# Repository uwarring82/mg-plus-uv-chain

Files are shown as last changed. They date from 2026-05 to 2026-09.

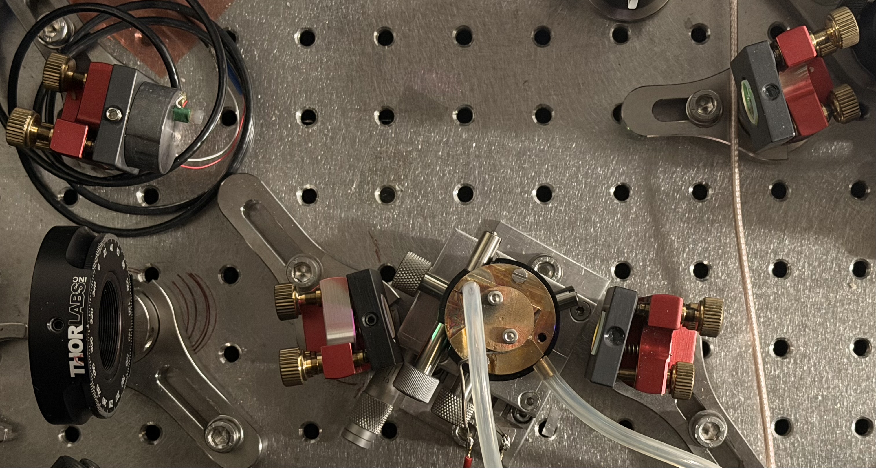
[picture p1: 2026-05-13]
docs/assets/components/home-built-doublers/bermuda-raman-bbo-doubler-2026-05.jpeg

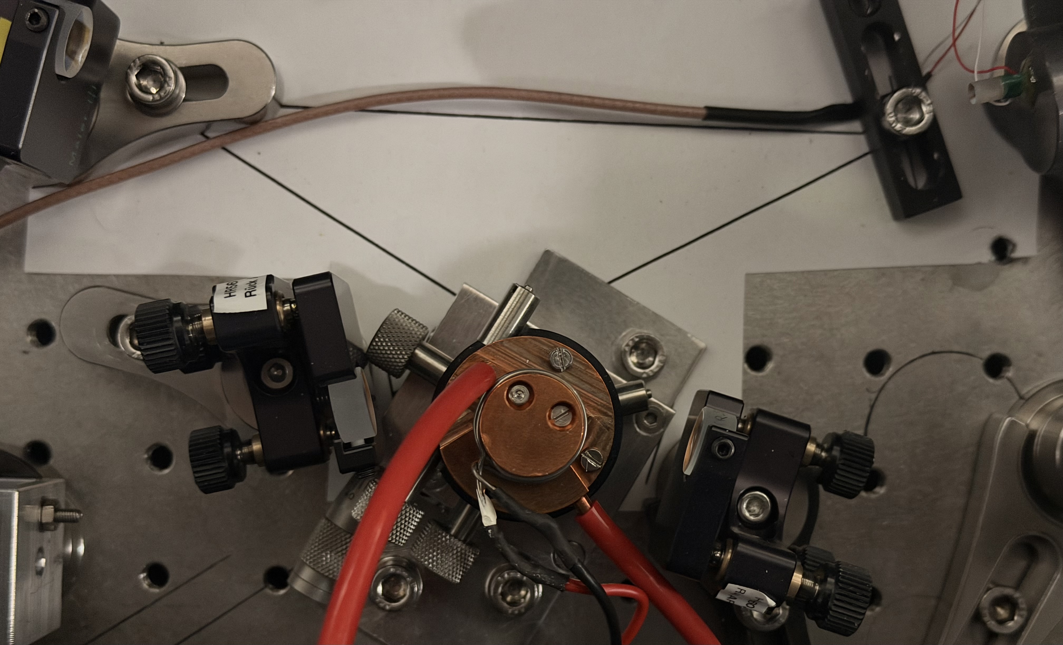
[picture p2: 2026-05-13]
docs/assets/components/home-built-doublers/bermuda-rd-bbo-doubler-2026-05.jpeg

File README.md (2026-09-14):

# mg-plus-uv-chain

UV source redesign for ²⁵Mg⁺ detection, cooling, and coherent control.

A reproducible, version-controlled, FAIR design effort to redesign the all-solid-state CW laser source producing radiation near 280 nm for trapped ²⁵Mg⁺. Successor to Friedenauer *et al.*, *Appl. Phys. B* **84**, 371 (2006).

**Status — checked 2026-09-09.** The [literature dossier index](docs/KD-2026-XXX-uv-280nm.md#entry-index) records **9 of 15 entries past SCAFFOLD** (8 POPULATING, 1 DRAFT). These are dossier topics, distinct from the **22 per-paper extraction files** under [data/literature/](data/literature/). The [September review card](logbook/2026-09-09-repository-review-task-card.md) tracks numerical corrections and documentation work; the [correction record](logbook/2026-09-09-public-record-corrections.md) records progress. The [inventory](docs/components/inventory.md#agile-receipt) includes the Agile mirror receipt and selected coating data.

Phase 2 baseline measurement remains unblocked. G1 and G2 remain OPEN; G3 has been CLOSED since 2026-05-01 (reference triple locked). Architecture-specific simulation and degradation-dependent comparison inputs remain subject to their [gate conditions](#status-of-kill-gates-charter-51). The Charter remains frozen at v1.0.

**Steward.** Ulrich Warring (Albert-Ludwigs-Universität Freiburg, AG Schätz).

**Project site (GitHub Pages).** [Project overview](https://uwarring82.github.io/mg-plus-uv-chain/), built from `main:/docs` using Jekyll. The site introduces the optics, calculations and current status. Borrowed visual assets use **Handbook (MIT)** licensing and **Model B (distributed copies pinned by checksum)**; attribution and hashes are in [asset provenance](docs/assets/SOURCE.md).

---

## Quick navigation

This repository is governed by the [Charter](CHARTER.md). The Charter is the canonical reference; this README is a navigational index.

**If you want to know…**

| Question | Look in |
|---|---|
| Why this redesign exists, and what it is *not* | [CHARTER.md §1, §3](CHARTER.md) |
| What constraints flow from the ion physics down to the source | [CHARTER.md §1.5](CHARTER.md) (Level 0 → Level 1 → Level 2) |
| What "≥ 500 mW at 280 nm" actually means | [CHARTER.md §2](CHARTER.md) and [`constraints/`](constraints/) |
| Which architectures are on the table | [CHARTER.md §4](CHARTER.md) (quadrupling / SFG / hybrid / direct deep-UV) |
| The phase plan and what blocks what | [CHARTER.md §5, §5.1, §5.3](CHARTER.md) (phases, kill-gates, gate closure protocol) |
| How architectures will be compared | [CHARTER.md §5.2](CHARTER.md) (six fixed scoring axes, reference-triple anchoring) |
| What "success" means | [CHARTER.md §6](CHARTER.md) |
| Known unsolved boundaries (14-GHz domain, UV degradation, coatings) | [CHARTER.md §8](CHARTER.md) |
| Governance, vetoes, logbook discipline | [CHARTER.md §9](CHARTER.md) |
| Why the Charter has the shape it does | [`logbook/2026-04-30-kickoff.md`](logbook/2026-04-30-kickoff.md) (nine-cycle deliberation history) |
| How students can learn, run notebooks and contribute | [Student tutorials](https://uwarring82.github.io/mg-plus-uv-chain/tutorials/) |
| Where the SHG mechanical drawings and machine-readable design records live | [SHG design archive](https://uwarring82.github.io/mg-plus-uv-chain/components/shg-designs.html) · [source records](data/designs/shg/) |
| How to cite this work | [`CITATION.cff`](CITATION.cff) |

---

## Repository layout

Selected paths present in the repository:

```text
mg-plus-uv-chain/
├── CHARTER.md                  Frozen at v1.0; canonical design document
├── README.md                   This file
├── CONVENTIONS.md              Units, code and contribution conventions
├── CITATION.cff                Software citation metadata
├── LICENSE                     MIT (code)
├── LICENSE-DOCS                Document-licence scope and prior declaration
├── LICENSES.md                 Licence map and pending assignments
├── endorsement.md              Historical scope and attribution record
├── src/
│   ├── parameters.py           SI constants and locked reference values
│   └── boyd_kleinman.py        One of the generic optical-model utilities
├── constraints/                Constraint derivations; draft status noted in each file
│   ├── raman-requirements.md
│   ├── loss-budget.md
│   └── phase-noise-budget.md
├── docs/
│   ├── KD-2026-XXX-uv-280nm.md  Literature dossier (Phase 1)
│   ├── architectures/          Candidate sketches and requirements
│   ├── components/             Baseline, stock inventory and seed-laser records
│   ├── tutorials/              Generated tutorials and supporting documentation
│   ├── hardware-status.md     Dated hardware record
│   └── status.md              Dated phase/gate snapshot
├── tests/                      Numerical tests and import guards; CI work in RC-06
├── notebooks/                  Tutorial sources, diagnostics and explorations
├── scripts/                    Rendering and conversion tools
├── data/
│   ├── README.md               Data layout and measurement-metadata conventions
│   ├── literature/             Per-paper extractions and notes
│   └── lab notes/              Converted lab records; private attachments excluded
└── logbook/
    ├── _templates/
    │   └── gate-closure.md     §5.3 template
    └── 2026-09-09-repository-review-task-card.md
```

**Planned, not yet present:** `data/baseline/` for Phase 2 measurement deposits,
and `docs/architecture-comparison.md`, `docs/stability-budget.md` and
`docs/degradation-protocol.md` as dedicated outputs. Current architecture
requirements live under [docs/architectures/](docs/architectures/); measurement
metadata conventions are in [data/README.md](data/README.md).

---

## Status of kill-gates (CHARTER §5.1)

| Gate | Blocks | Status |
|---|---|---|
| G1 | Phase 3 architecture-family-specific simulation | OPEN — awaiting Phase 2 attribution of 14-GHz domain |
| G2 | Phase 4 / Phase 5 acceptance of degradation rate | OPEN — awaiting Phase 2 §8.2 protocol reproducibility |
| G3 | Phase 4 architecture comparison | **CLOSED** 2026-05-01 — see [`logbook/2026-05-01-gate-g3-closure.md`](logbook/2026-05-01-gate-g3-closure.md) |

Gate closure requires the recorded acknowledgement defined in Charter §5.3, using [`logbook/_templates/gate-closure.md`](logbook/_templates/gate-closure.md).

---

## How to contribute

Ulrich Warring is accountable for this project. External issues, suggestions and technical reviews are welcome. Changes to Charter §1.5 Level 0/1 constraints, §6 success criteria or gate closures require a recorded review under Charter §9. The historical `council-3` issue label identifies that review process; it does not imply a separately staffed committee.

The Charter is frozen at v1.0. Revisions require a documented v1.x cycle.

---

## Citation

If this repository or its outputs inform your work, please cite as in [`CITATION.cff`](CITATION.cff). A Zenodo DOI has not been verified. No tags or GitHub releases were present on the remote when checked on 2026-09-09. Cite the repository and the commit used; the frozen Charter version is not evidence of a tagged software release.

## License

Licensing is specified by content in the [licence map](LICENSES.md):

- **Coastline — CC-BY-SA-4.0:** mapped framework and navigation documents, including this README; attribution and ShareAlike apply.
- **Sail — CC-BY-NC-SA-4.0:** mapped authored analyses; attribution, NonCommercial and ShareAlike apply.
- **Handbook — MIT:** borrowed site assets and mapped layouts. **Code — MIT.**
- **Data — CC-BY-4.0:** mapped structured extractions and measurement data.

These are licence categories, not ratings of scientific confidence. The map
records remaining scope questions and prior declarations; third-party sources
retain their own terms. [LICENSE-DOCS](LICENSE-DOCS) explains document scope.

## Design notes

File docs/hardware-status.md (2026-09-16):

---
layout: default
title: Hardware status — VECSEL seed fleet
description: What has been built and what is open on the in-house VECSEL seed lasers (1118 nm cooling/detection/Raman and 1141 nm photoionisation), distilled from the lab record. Operational snapshot, sanitised; distinct from the governance Status page.
---

<p class="endorsement"><strong>Endorsement Marker.</strong> Local operational snapshot — AG Schätz stewardship. This page summarises the build/operations state of the in-house VECSEL seed fleet at a sanitised level (roles, not individuals; no procurement or facility detail). It is not a Phase 4 input and does not alter the reference triple. For repository governance state (kill-gates, phases, dossier) see the <a href="status.html">Status</a> page.</p>

<p class="eyebrow">Snapshot · 2026-06-26 · DRAFT</p>

# VECSEL seed fleet — what's done, what's open.

Distilled from the internal lab record (2021–2026) into a sanitised summary, so the group
can see at a glance what has been built and what is still open. Figures are
**[in-house, unverified]** pending cross-check against the primary logbook; the provenance
artefact is [`data/lab notes/2026-06-rnd-vecsel-channel-record.md`](https://github.com/uwarring82/mg-plus-uv-chain/blob/main/data/lab%20notes/2026-06-rnd-vecsel-channel-record.md).

For *how* the lasers work, see the [VECSEL systems tutorial](tutorials/vecsel-systems.html).

---

## The fleet *Sail*

<p class="classification classification--sail">Sail · operational state; the testable physics is in the tutorial and the cited lab notes.</p>

| Unit | Wavelength / role | State (2026-06) |
|---|---|---|
| **"Heidi" (V#2)** | **1141 nm** photoionisation → extra-cavity **LBO → ≈570 nm** (toward 285 nm) | Lasing; doubling stage commissioned 2026 (≈570 nm output measured) |
| **1118 nm units (incl. V#4)** | cooling / detection / repump / Raman seed → 280 nm | In operation; V#4 in use by a downstream experiment |
| **V#5** (1118 nm, student build) | cooling/detection-class seed | Operating ~2.6 W; Lyot-filter re-fit in progress (see open items) |
| **"NeXt"** (1118 nm, bachelor build) | next-generation low-noise platform | Re-lased; integrated onto its cold plate |

---

## What has been done *Coastline + Sail*

<p class="classification classification--coastline">Coastline · the linewidth lineage is the published in-house record (tutorial §3.3).</p>

- **Linewidth driven down > 10× across four builds** — 1.6 MHz (2021) → ~300–400 kHz (2023) → **101(8) kHz locked (2025)**, by closing thermal, mechanical, and cooling-water noise sources (tutorial [§3.3](tutorials/vecsel-systems.html)).
- **A facility-plumbing finding** — a chiller on/off cycle drove ~200 MHz of frequency oscillation; replacing the cooling loop removed it (factor-5 short-term gain).
- **Multiple operating units** built and characterised at 1118 nm (cooling/detection/Raman) plus the 1141 nm photoionisation unit.
- **1141 nm → ≈570 nm doubling stage** stood up in 2026 (extra-cavity LBO ring; ~110 mW measured in one run) — the first SHG step toward 285 nm.
- **1118 nm operating point** recently re-confirmed on the V#5 build (~2.6 W near 267.744 THz, 2026).

---

## Open items *Sail*

<p class="classification classification--sail">Sail · current work fronts; none of these alters Charter Level 0/1 constraints or the kill-gate state (see <a href="status.html">Status</a>).</p>

**Measurement gaps (also tracked in the tutorial §3.5 / §5):**
- **Seed frequency-noise PSD** across the doubling-cavity servo band — unmeasured. The closed-loop bandwidth of each doubling cavity is itself unmeasured; Friedenauer 2006's ≈ 18 kHz is a loaded piezo resonance, not a loop bandwidth (see [planned cavity-lock electronics](components/shg-designs.html#cavity-lock-electronics)).
- **Downstream UV relative-intensity noise** at the experiment — unmeasured.
- A true **sub-100 kHz intrinsic linewidth** — not yet independently proven (needs delayed self-heterodyne or a beat note).
- **1141 nm "Heidi"** full characterisation — linewidth, output power, and the ≈570 nm → 285 nm second stage still to be recorded.

**Build / commissioning fronts** (engineering status; none affects the physics above):
- **1141 → 570 nm doubling lock** under stabilisation (commissioning in progress).
- **V#5 (student build):** intracavity birefringent (Lyot) filter re-fit in progress; single-mode hold time temporarily reduced in the interim.
- **New gain-chip mounting:** a freshly-mounted chip shows a slow (~10 min) power/frequency settling, under characterisation.
- **"NeXt":** water-cooling vibration test and control-board revision pending.

---

## See also

- [Status](status.html) — repository governance state (kill-gates, phases, dossier, tests).
- [VECSEL systems tutorial](tutorials/vecsel-systems.html) — how the seed lasers work and what limits their linewidth.
- [`data/lab notes/`](https://github.com/uwarring82/mg-plus-uv-chain/tree/main/data/lab%20notes) — the sanitised in-house extractions every figure here is drawn from.

---

[← Home](index.html) · [Status →](status.html) · [VECSEL tutorial →](tutorials/vecsel-systems.html)

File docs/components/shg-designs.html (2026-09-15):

--- layout: default title: SHG mechanical designs — AG Schaetz description: Original LBO and BBO drawings, open CAD exports, and a machine-readable catalogue with provenance and conversion limitations. ---

AG Schaetz · Mechanical design archive · 2020–2021

# Inside our SHGs

Explore the cavities, crystal mounts and optical assemblies behind the laboratory's frequency-doubling chain. Each design has an unchanged original, an open drawing export and a record of what the conversion preserves.

{{ site.data.shg.designs.size }} drawings · Author: AG Schaetz · Publication authorized by Ulrich Warring, 14 September 2026.

Download JSON catalogue JSON Schema Source archive & YAML records (https://github.com/uwarring82/mg-plus-uv-chain/tree/main/data/designs/shg)

Readable previews; conversion fidelity unverified.

These views are reconstructed from cached drawing blocks. An independent CAD rendering has not yet been checked. Some engineering symbols may appear as letters because the original AIGDT font is unavailable; view placement and clipping may differ. Use the original CAD for manufacturing decisions.

This archive documents existing designs. It is not a build commitment for the next-generation source, and correspondence to installed hardware requires a bench check.

How to read and reuse this archive

DWG is the byte-identical source. DXF.gz is an ASCII DXF export compressed for download; decompress it before opening it in CAD software. SVG, PDF and PNG are preview derivatives. Source files, exports and previews have individual SHA-256 checksums in the catalogue.

DWG JSON.gz preserves the source reader's object graph for programmatic use: handles, coordinates, classes and opaque proxy payloads. It is a drawing export under CERN-OHL-S-2.0. The separate JSON catalogue contains CC-BY-4.0 metadata.

The source uses Inventor proxy objects with cached linework. The exports preserve accessible drawing entities and annotations; editable native models and STEP exports are not established. Inspection records expose annotation text with entity handles, entity counts, layout decisions and conversion limitations.

The block audit (https://github.com/uwarring82/mg-plus-uv-chain/blob/main/data/designs/shg/block-audit.json) accounts for the identical entity deficits in eight drawings: ODA omits two repeated template blocks, a sheet border and historical title block. Their stored insertion backlinks are absent from the parsed source graph. This identifies the omitted content; proxy semantics and rendering fidelity remain unverified.

Design only means no installed-hardware association has been established. Provisionally associated requires cited evidence. Confirmed requires a bench check. A match to a thesis drawing is not hardware confirmation.

Guth2021 §2.2.2 is a starting reference. The geometry extraction (https://github.com/uwarring82/mg-plus-uv-chain/blob/main/data/literature/Guth2021/geometry.yaml) preserves printed values, including the unresolved LBO curvature entry of 50 cm in Table 3. No drawing-to-thesis dimensional match is asserted yet.

Drawings, exports and preview images: CERN-OHL-S-2.0 (https://ohwr.org/licences/). Catalogue metadata: CC-BY-4.0. Page narrative: CC-BY-SA-4.0. Tooling: MIT. See the scoped licence notice (https://github.com/uwarring82/mg-plus-uv-chain/blob/main/data/designs/shg/LICENSE.md) and decision and validation record (https://github.com/uwarring82/mg-plus-uv-chain/blob/main/logbook/2026-09-14-shg-design-publication.md).

Cavity-lock electronics (planned)

AG Schaetz plans to lock the LBO and BBO cavities with the digital PID controller developed at PTB and described by Hannig et al. (2018) (https://doi.org/10.1063/1.5005515). Later work calls it "PTB-PID". The technical description below comes from public sources. No settings, measured lock performance or hardware assignment are reported for our cavities, and the published source code has not been matched to the firmware on the laboratory units. This plan leaves project parameters and gate status unchanged.

Published design. Hannig et al. lock a Brewster-cut BBO cavity (626 nm → 313 nm) using a Hänsch–Couillaud error signal from a polarization analyser and differential photodiode. The PI output drives a piezo-mounted cavity mirror; the D term is set to zero for cavity locking. The controller is a modified STEMlab 125-14 (formerly Red Pitaya). The PID algorithm runs in the FPGA of a Xilinx Zynq-7010 system-on-chip, independently of the embedded software. It uses two fast analog input channels and two output channels at 125 MS/s with 14-bit nominal resolution. Parameters are set through a web application, a serial connection or a standalone touchscreen and rotary encoder. The paper explicitly states that the board hardware is not open source; the modified application source is publicly available (§IV.C).

Additions to the stock PID. The controller adds a master gain, a second integrator, an output offset, extended parameter ranges and an integrated signal generator. It can save settings and digitally limit its output. An auxiliary intensity input enables automatic relocking by distinguishing TEM00 resonances from parasitic signals, and it provides automatic integrator reset and sample-and-hold. The standalone box amplifies the DAC output eightfold (2 Vpp to 16 Vpp) for the piezo and includes a modification that reduces DAC output noise.

Reported limits and results. The controller's 155 ns group delay suggests a maximum closed-loop bandwidth of a few MHz; effective converter resolution is below 14 bits (§IV.D.2). This is a controller-delay estimate: the published piezo connection also includes a 21.2 kHz low-pass filter (§IV.C.1). In Hannig's cavity, a broad resonance near 17 kHz set the upper limit for locking bandwidth; the authors attribute it provisionally to the mirror, piezo actuator and holder (§V.B). They report 130 h of uninterrupted lock and, in a separate acceleration test, lock retention up to about 1 g with output-power variation at the 10 % level (§V.A, C).

Friedenauer (2006) reports a similar loaded piezo resonance of about 18 kHz for the LBO cavity (§3, p. 372). That resonance is not a measurement of closed-loop bandwidth. Neither paper establishes the bandwidth of our planned locks; that requires measurements of the assembled systems.

Public sources.

- S. Hannig et al., "A highly stable monolithic enhancement cavity for second harmonic generation in the ultraviolet," Rev. Sci. Instrum. 89, 013106 (2018), doi:10.1063/1.5005515 (https://doi.org/10.1063/1.5005515) (published article: CC BY 4.0). An accessible 2017 preprint (https://arxiv.org/abs/1709.07188) is also available.
- Controller source cited by the paper (ref. 67): Julia-F/RedPitaya at 7938c27 (https://github.com/Julia-F/RedPitaya/tree/7938c27fc030ca5d8d13b1731f559e33585458f1), a snapshot dated 26 May 2016. The PID application is in apps-free/pid2 and the FPGA logic in fpga/rtl/red_pitaya_pid2*.v. Its COPYING (https://github.com/Julia-F/RedPitaya/blob/7938c27fc030ca5d8d13b1731f559e33585458f1/COPYING) grants BSD terms for an explicit directory list whose names differ from these paths. Licence coverage for the modified controller has not been established here; check the applicable notices before reuse.
- J. Fenske, "Implementierung eines digitalen PID-Reglers mit dem Entwicklungsboard Red Pitaya," BSc thesis, Ostfalia Hochschule für angewandte Wissenschaften (2015). Bibliographic citation from Hannig et al., ref. 42; the thesis itself was not reviewed.
- P. Knauer, "Stabilisation of Thermal Drifts in a Femtosecond Enhancement Cavity," BSc thesis, University of Heidelberg (2019), PDF (https://pure.mpg.de/rest/items/item_3048433_1/component/file_3048434/content), §§3.2 and 4.1. It describes an MPIK adaptation of PTB-PID for a Pound–Drever–Hall lock; the corresponding code is in PatKnauer/redpitaya (https://github.com/PatKnauer/redpitaya).

Find a design Stage or role

{{ site.data.shg.designs.size }} designs

{% for design in site.data.shg.designs %} {% assign first = design.previews | where: "qualifies", true | first %}

{{ design.id }} · {{ design.stage | escape }} · {{ design.kind | escape }}

## {{ design.title_en | escape }}

{{ design.title_de | escape }}

{% if first %} Unverified reconstructed drawing of {{ design.title_en | escape }}, sheet {{ first.name | escape }} {% endif %}

{{ design.hardware_association.status | replace: '_', ' ' | capitalize }} · Preview unverified

Original DWG DXF.gz DWG JSON.gz {% if first %}PDF preview{% endif %}

All sheets & provenance

Original name: {{ design.original_filename | escape }}

{{ design.previews.size }} recorded layouts · Native unit: {{ design.units.native | escape }} · {{ design.classification.basis | escape }}

{% for observation in design.conversion_observations %}

Conversion note: {{ observation | escape }}

{% endfor %}

Conversion and annotation record · Independent source-reader record

{% if design.block_audit_result %}

Template-block audit ({{ design.id }})

{% endif %} {% for sheet in design.previews %} {% if sheet.qualifies %}

{{ design.title_en | escape }}: sheet {{ sheet.name | escape }}, unverified preview

{{ sheet.name | escape }} · SVG · PDF · Unverified

{% else %}

{{ sheet.name | escape }}: {{ sheet.reason | replace: '_', ' ' | escape }}

{% endif %} {% endfor %}

{% endfor %}

No designs match. Try a different name or stage.

Related records: BBO photographic survey · Hardware inventory · Friedenauer reference chain.

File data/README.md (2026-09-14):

# Data — `data/`

**CHARTER §7 FAIR commitment:** raw and processed data separated; metadata schema declared here.

This directory holds all measurement and reference data for `mg-plus-uv-chain`. Empty at v1.0 cut; populated during Phase 1 (literature parameter extraction) and Phase 2 (baseline measurements).

---

## Layout

```
data/
├── README.md                ← this file (metadata schema)
├── baseline/                ← Phase 2 measurements on the existing chain
│   └── YYYY-MM-DD_<topic>/
│       ├── raw/             ← unmodified instrument output
│       ├── processed/       ← analysed; provenance preserved
│       └── metadata.yaml    ← per-dataset metadata (schema below)
└── literature/              ← parameters extracted from cited works
    └── <citation-key>/
        ├── extracted.yaml   ← parameter table
        └── notes.md         ← extraction commentary
```

Per CHARTER §7: raw and processed data are kept in sibling directories, never co-mingled. Provenance from raw → processed must be reconstructible from committed code.

---

## Metadata schema (`metadata.yaml`)

Every measurement dataset under `baseline/` carries a `metadata.yaml` file at its root with the following fields:

```yaml
# Required
dataset_id: "YYYY-MM-DD_<topic>"           # matches directory name
date: "YYYY-MM-DD"                         # ISO 8601
operator: "<name>"                         # who took the data
charter_phase: 2                           # which CHARTER phase this serves
charter_section_refs:                      # which CHARTER sections it informs
  - "§8.1"                                 # e.g. 14-GHz domain discriminant
  - "§8.2"                                 # e.g. degradation tuple

# Apparatus state — reproducibility anchor
apparatus:
  source_chain: "<short description>"      # e.g. "1118 nm fibre amp + 2× SHG, BBO at UV stage"
  source_version: "<git tag or label>"     # if a software-controlled chain
  enclosure_atmosphere: "N2 | O2 | dry-air | ambient"
  ambient_temperature_C: <float>           # if relevant
  exposure_history: "<free-form>"          # CHARTER §8.2: cumulative UV exposure context

# Instruments — every channel that produced a value
instruments:
  - role: "<e.g. UV power meter>"
    make_model: "<vendor / model>"
    serial: "<sn or label>"
    last_calibration: "YYYY-MM-DD"

# Measurement parameters — what was scanned
scan:
  type: "<e.g. cavity-length, polarisation, intra-cavity-intensity>"
  variable: "<symbol>"
  units: "<SI>"
  range: [<low>, <high>]
  step: <float>
  averaging: <int>                          # samples per point

# Data files — pointer with units
files:
  - path: "raw/<file>"
    columns:
      - name: "<symbol>"
        units: "<SI>"
        description: "<one line>"

# Discriminant hypothesis (if applicable; CHARTER §8.1)
discriminant:
  hypothesis_under_test: "<text>"
  expected_signature: "<text>"
  outcome_classification: "Resolved | Operationally bounded | Underdetermined | TBD"

# Provenance — raw → processed
processing:
  pipeline: "<git path to processing script>"
  pipeline_commit: "<sha>"
  random_seed: <int>                        # required if any stochastic step
  inputs: ["raw/<file>", ...]
  outputs: ["processed/<file>", ...]

# Notes
notes: |
  Free-form commentary. Anything that would be needed to interpret this
  dataset six months later, or by an outside reader, goes here.
```

All units are SI per CONVENTIONS §1. Derived-unit presentation (mW, nm, GHz) lives in plotting code, not in the metadata file.

---

## Literature data (`literature/<citation-key>/`)

Per-paper parameter extractions live under `literature/<citation-key>/extracted.yaml`:

```yaml
citation_key: "Friedenauer2006"             # matches CITATION.cff and dossier
doi: "10.1007/s00340-006-2274-2"
extracted_by: "<name>"
extracted_on: "YYYY-MM-DD"
charter_section_refs: ["§2", "§4", "§8.1"]

parameters:
  - symbol: "P_UV"
    value: 0.275
    units: "W"
    location_in_paper: "Abstract; Fig. 3"
    notes: "Reported source-side; loss budget to ion not stated."
  - ...
```

Vendor / batch sensitivity, where the paper reports it, must be captured (CHARTER §5 Phase 1 evidence-table requirement).

## Design data (`designs/`)

The [AG Schaetz SHG archive](designs/shg/README.md) separates unmodified
CAD in `designs/shg/raw/` from exports and inspection records in
`designs/shg/processed/`. Its canonical `catalogue.yaml` is validated by
`catalogue.schema.json`; this design schema is separate from the baseline
measurement schema above.

Each drawing also has a compressed ASCII DXF and a compressed GNU LibreDWG
JSON object graph. The latter exposes source objects and opaque payloads to
programmatic readers; it carries the hardware licence. Compact inspection
JSON and the generated catalogue carry the metadata licence.

Required design records include stable IDs independent of filenames, original
names and archive-name encoding, author attribution, publication/licence
disposition, checksums, part/assembly classification, source and converter
date metadata, native units, hardware-association evidence, export inventories,
layout decisions, conversion losses and preview references. Original CAD units
and raw annotations are preserved; normalized extracted quantities use SI.
Hardware confirmation requires bench evidence. Drawing tags `D`, `D*`, `OPEN`
identify direct, ambiguous/inferred and unresolved evidence.

`scripts/shg_designs.py site` generates `docs/_data/shg.yml` and the public
JSON catalogue from canonical YAML. Its `check` command verifies schema,
file hashes and generated-data freshness. The new `tests/test_shg_designs.py`
covers these contracts. Licence scope for CAD, metadata, derivatives and
narrative is explicit in [LICENSES.md](../LICENSES.md); it is not inferred
from the existing measurement-data or site-asset categories.

---

## Charter compliance

- **Pre-G1**: data may be deposited freely; data ingest does not constitute architecture-family-specific simulation under CHARTER §5.1.
- **Discriminant scans (CHARTER §8.1)**: deposited under `baseline/`; `outcome_classification` tracks per-scan progress toward G1 closure.
- **Degradation protocol (CHARTER §8.2)**: time-resolved {power, M², phase noise, polarisation} mandatory. Single-number degradation rates without protocol attribution will be rejected per the Charter.
- **§9 trigger question**: depositing data does not by itself change a Level 0/1 parameter. If interpreting the data prompts a constraint change, that's an architectural decision and lives in `/logbook/`.

---

End of `data/README.md`.

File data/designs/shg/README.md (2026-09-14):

# AG Schaetz SHG design archive

**Author attribution:** AG Schaetz. **Publication authorized:** Ulrich Warring,
2026-09-14. [Decision and work record](../../../logbook/2026-09-14-shg-design-publication.md)
and [publication follow-ups](../../../logbook/2026-09-14-shg-publication-follow-ups.md).

The archive preserves 28 drawings supplied as `SHG.zip`. Originals retain
their exact bytes under stable IDs. The ZIP checksum, original filenames,
original filename bytes, local ZIP timestamps and individual checksums are
in [`catalogue.yaml`](catalogue.yaml). Finder timestamps and drawing creation
dates are separate evidence; ZIP timestamps have no recorded timezone.
`.DS_Store` and `__MACOSX` are excluded. IDs are an explicit registry, not
calculated from filenames or contents.

## Formats and limitations

- `raw/SHG-NNN.dwg`: unmodified AC1032 DWGs.
- `processed/SHG-NNN/SHG-NNN.dxf.gz`: direct ODA ACAD2018 ASCII DXF export,
  compressed without modifying its contents. Decompress with `gzip -dk` or
  Python `gzip.decompress`. Both compressed and uncompressed hashes are recorded.
- `processed/SHG-NNN/source-inspection.json`: source-side counts, original
  DWG date fields and warnings from GNU LibreDWG.
- `processed/SHG-NNN/SHG-NNN.dwg.json.gz`: the complete GNU LibreDWG reader
  object graph, including handles, coordinates, source classes and opaque
  proxy payloads. Decompress, then parse as JSON. This is a drawing export
  under CERN-OHL-S-2.0, distinct from the CC-BY-4.0 catalogue metadata.
- `processed/SHG-NNN/inspection.json`: DXF entity inventories, annotation
  text with source handles, references, reconstruction placements and losses.
- `docs/assets/shg/SHG-NNN/`: generated PDF/SVG/PNG previews for each
  qualifying sheet. These are **unverified reconstructed previews**.

The drawings use Inventor-specific proxy objects with cached linework and
annotation blocks. The direct exports preserve those blocks but do not
constitute editable native Inventor models. Ordinary layout rendering is
empty without exposing the cached blocks. The preview tool decodes the
observed unit-transform proxy variant, exposes blocks at their stored
coordinates, and applies source viewport associations, scale and clipping.
Unfamiliar transforms stop processing. This restricted decoder and the
resulting views remain unverified against an independent CAD engine.
The AIGDT engineering
symbol font is unavailable; some symbols appear as letters. **Use original
CAD and an independent CAD reference before machining or relying on dimensions.**

LibreDWG provides a second parse, not an independent rendering. Reader
success, matching counts and visual legibility do not establish fidelity.
Source-side dates are retained as raw day/millisecond pairs; ODA can reset
the DXF date fields, so those are labelled converter metadata. Native solids
and STEP availability are unresolved inside the proxy payloads. No STEP or
interactive 3D export is asserted.

The [block audit](block-audit.json) identifies the identical deficit in eight
drawings as omitted sheet-border (`D3`) and historical title-block (`FC`)
definitions. Both source names are `*I`; preserved handles distinguish them.
Their recorded insertion backlinks are absent from the parsed source graph.
The full deficit is accounted for, but opaque proxy references and visual
effect still need an independent CAD check. Reproduce with
`python -m scripts.shg_block_audit --check` in the full SHG environment.

## Native source and reference-rendering follow-up

No `.iam`, `.ipt`, `.idw` or `.ipj` files were found in the supplied archive,
repository or the Desktop filename search on 2026-09-14. Their location
remains an open request to the Steward; this is not a claim about other
laboratory storage. The preferred handover is an Inventor
[Pack and Go package](https://help.autodesk.com/cloudhelp/2025/ENU/Inventor-Help/files/GUID-730304AA-13BD-467B-9351-C7C1362876BD.htm)
with assemblies, parts, drawings, the project file and resolvable references.
Include referencing drawings and required libraries when collecting the
package, and record the authoring version and any missing references/fonts.

Receiving native files alone does not verify these previews. Render the
corresponding sheets with Inventor, or use an independent AutoCAD rendering
of the original DWGs, then compare dimensions, symbols, layouts and views
per file. Native assembly relationships and STEP exports require separate
checks. Hardware confirmation still requires bench evidence.

## Records and evidence

[`catalogue.schema.json`](catalogue.schema.json) validates the YAML record.
Drawing evidence tags are `D` (direct), `D*` (ambiguous/inferred), `OPEN`
(unresolved). These are separate from hardware association: `design_only`,
`provisionally_associated`, `confirmed`. The last requires bench evidence.
Guth2021 correspondence alone cannot confirm installed hardware; the
[targeted geometry extraction](../../literature/Guth2021/geometry.yaml)
records printed parameters and unresolved discrepancies.

The initial numerical extraction is deliberately limited. Inspection reports
preserve all accessible annotation text and handles, including exploded
dimension labels, but do not turn a label into a measured feature. Materials
and tolerances remain OPEN unless supported by a title block. Native CAD
units are retained; normalized numerical catalogue fields use SI.

## Reproduction

For the complete SHG test and rendering environment, run
`python -m pip install -e '.[test,shg]'` from the repository root. The `shg`
extra pins the same drawing dependencies as
[`scripts/requirements-shg.txt`](../../../scripts/requirements-shg.txt).
The standard `test` extra does not install ezdxf: the two viewport tests
skip without it. Run pytest with `-rs` to see these skip reasons. The
original **14 passed** result used the full drawing environment; the
standard environment instead reports **12 passed, 2 skipped** for that
original test file. There is currently no CI enforcing these checks.
ODA File Converter 27.1.0 and GNU LibreDWG 0.14 are external local tools;
neither tool nor the local Guth thesis PDF is redistributed here.

```sh
python scripts/shg_designs.py ingest /path/to/SHG.zip
python scripts/shg_designs.py convert --oda /path/to/ODAFileConverter --output /tmp/shg-dxf
python scripts/shg_designs.py inspect-source --reader /path/to/dwgread
python scripts/shg_designs.py process /tmp/shg-dxf
python scripts/shg_designs.py site
python scripts/shg_designs.py check
python -m pytest tests/test_shg_designs.py
```

`site` writes `docs/_data/shg.yml` and `docs/assets/shg/catalogue.json` from
canonical YAML. `check` validates the schema, original/export/preview hashes
and generated record freshness. Conversion is separate from website
generation, so checking or publishing the catalogue needs no proprietary
converter. Font availability can change rendering; record it when regenerating.

## Licence

DWGs, derived drawing exports and previews: **CERN-OHL-S-2.0**.
Catalogue metadata: **CC-BY-4.0**. This narrative: **CC-BY-SA-4.0**.
Scripts, schema and tests: **MIT**. See [LICENSE.md](LICENSE.md) for scope,
notices and the source location. Vendor components retain any applicable
third-party notices; this record makes no completeness claim for fabrication.

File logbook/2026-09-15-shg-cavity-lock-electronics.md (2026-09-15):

# SHG catalogue: planned cavity-lock electronics

**Date:** 2026-09-15\
**Steward:** Ulrich Warring\
**SHG design author attribution:** AG Schaetz\
**Licence:** CC-BY-SA-4.0\
**Starting revision:** `12dffc02c4ea57602e1b44cebf443146256635d0`\
**Status:** Published; local checks and live GitHub Pages verification passed.

## Charter §9 triggers

- Affects Level 0 parameters? No.
- Affects Level 1 parameters? No.
- Affects success criteria or gate state? No.

G1 and G2 remain OPEN. G3 remains CLOSED (2026-05-01). This entry records
presentation of the Steward's controller plan and corrections to literature
descriptions. It does not establish controller settings, performance,
firmware identity, installed-hardware association or a next-generation
architecture selection. All 28 drawing records remain `design_only` and
their previews remain `unverified`.

## Decisions

The Steward supplied an uncommitted catalogue subsection for visitors who
cannot access the laboratory's private controller records. The existing
authorization to publish SHG work and instruction to keep logbook entries
apply to this follow-up.

1. Keep the collapsible **Cavity-lock electronics (planned)** section after
   **How to read and reuse this archive**, at
   [`shg-designs.html#cavity-lock-electronics`](../docs/components/shg-designs.html#cavity-lock-electronics).
   The catalogue remains the public reference; no separate page is needed.
2. Omit the private repository's name and link. The public explanation is
   self-contained. No private repository content was accessed in this review
   or included in these changes.
3. Add a pointer from the photo survey's **HC servo electronics and bandwidth**
   gap. The stated intention is to use the PTB digital PID for LBO and BBO
   cavity locks. This intention comes from the Steward; technical descriptions
   and reported results come from the cited public literature.
4. Record the work here despite the absence of parameter changes, following
   the Steward's instruction to keep SHG work records. The existing catalogue
   narrative assignment and this entry are CC-BY-SA-4.0; the root licence map
   explicitly lists this new entry. Existing component-page and literature-note
   assignments are preserved. Public citations do not relicense third-party
   hardware or software.

## Source review and qualifications

The local publisher copy of
[Hannig et al. (2018)](https://doi.org/10.1063/1.5005515), §§IV–V,
pp. 013106-5–8, was checked for the controller and lock claims. The catalogue
also links the [2017 arXiv preprint](https://arxiv.org/abs/1709.07188) for
public access when the publisher blocks a request.

- §IV.C specifies FPGA PI operation with D set to zero, the modified
  STEMlab 125-14, two fast input and two output channels, interfaces,
  controller additions and eightfold output amplification. Its hardware
  subsection explicitly says that the board hardware is not open source.
  The earlier blanket description in
  [`Hannig2018/notes.md`](../data/literature/Hannig2018/notes.md) is corrected;
  the machine-readable extraction remains a scaffold.
- §IV.D.2 derives a few-MHz controller-bandwidth estimate from 155 ns group
  delay. The complete system also includes the 21.2 kHz piezo low-pass filter
  described in §IV.C.1. The estimate is not presented as measured cavity
  bandwidth.
- §V.B identifies a broad resonance near 17 kHz as the lock-bandwidth upper
  limit, probably due to the mirror, piezo and holder. The 130 h lock record
  (§V.A) and acceleration test up to about 1 g (§V.C) are separate results
  from the published 313 nm cavity.
- Friedenauer 2006 §3, p. 372, reports an approximately 18 kHz **loaded LBO
  piezo resonance**, not a measured closed-loop bandwidth. Similar resonance
  frequencies do not establish identical loop limits or any performance of
  the laboratory units. The linked baseline, photo survey and seed-laser
  pages were corrected where they equated that resonance with a measured
  loop bandwidth or assigned it to fielded doublers. The seed-linewidth
  budget and project parameters were not changed.

The code cited by Hannig ref. 67 is linked at
[`Julia-F/RedPitaya`, commit `7938c27fc030ca5d8d13b1731f559e33585458f1`](https://github.com/Julia-F/RedPitaya/tree/7938c27fc030ca5d8d13b1731f559e33585458f1),
dated 26 May 2016. Public `COPYING`, `apps-free/pid2/src/pid.c` and
`fpga/rtl/red_pitaya_pid2.v` were inspected. The explicit BSD directory list
uses different names from the modified controller paths; the two source
headers do not settle coverage. The page states this uncertainty without
using GitHub's automatic licence detection as a legal conclusion. No code
or firmware is imported, and no lab firmware match is claimed.

Fenske's 2015 thesis is cited through Hannig ref. 42; its text was not
reviewed. Knauer's public
[2019 thesis](https://pure.mpg.de/rest/items/item_3048433_1/component/file_3048434/content),
§§3.2 and 4.1 (pp. 20 and 23), and
[`PatKnauer/redpitaya`](https://github.com/PatKnauer/redpitaya) establish the
later PTB-PID/MPIK-PID terminology. This adaptation uses a
Pound–Drever–Hall error signal; it is not evidence of the laboratory's
Hänsch–Couillaud implementation.

## Validation and publication

- `.venv/bin/python -m pytest -q`: **275 passed, 3 skipped**. The existing
  block-audit regeneration and two viewport/proxy tests skip because ezdxf
  is absent from the standard environment. No new test is claimed to cover
  the page's scientific prose.
- The catalogue and default layout rendered with **Liquid 4.0.4** in strict
  parsing/filter mode using `docs/_config.yml` and `docs/_data/shg.yml`.
  This is a local template check, not a local Jekyll build.
- Parsed rendered HTML has balanced tags, unique IDs, 28 design cards, the
  collapsed electronics section in the intended position, and valid local
  fragment targets. Survey and seed-page pointers target the new anchor.
  The private repository identifier is absent from the rendered catalogue.
- Public source checks without authentication return HTTP 200 for the
  pinned code snapshot, its `COPYING`, the arXiv preprint, Knauer's PDF and
  the MPIK code repository. The DOI redirects to the correct publisher
  article, which returns HTTP 403 to the scripted request; the preprint is
  provided as an alternative access route.
- `git diff --check` passes. The new logbook entry is explicitly present in
  `LICENSES.md`. No drawing, export, preview, generated catalogue, simulation
  or parameter data changed.

The existing GitHub Pages source was confirmed as `main:/docs` (legacy
build). Documentation commit
`7a4db92e5cc3cfc24a481171163f55ee5d7e2af0` was pushed to `main`; GitHub Pages
reports that exact commit **built**, with no error, at
2026-09-15 16:07:51 UTC. The first HTTP check during the build still served
the preceding page; checks after completion passed.

The live
[catalogue section](https://uwarring82.github.io/mg-plus-uv-chain/components/shg-designs.html#cavity-lock-electronics)
matches the local rendered section byte for byte, retains all 28 cards and
contains no private repository identifier. Public HTTP checks also confirm
the corrected
[photo survey](https://uwarring82.github.io/mg-plus-uv-chain/components/home-built-doublers.html),
[Friedenauer baseline](https://uwarring82.github.io/mg-plus-uv-chain/components/friedenauer-baseline.html#b2-piezo-and-mount)
and [seed-laser page](https://uwarring82.github.io/mg-plus-uv-chain/components/seed-lasers.html).
The survey/seed pointers resolve to the new section after Jekyll's relative-link
rewriting, and the baseline anchor exists. These are rendered-content and
HTTP checks; no interactive browser test or laboratory validation is claimed.

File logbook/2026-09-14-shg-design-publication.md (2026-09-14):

# SHG design archive: publication and implementation record

**Date:** 2026-09-14\
**Steward:** Ulrich Warring\
**Design author attribution:** AG Schaetz (as explicitly directed by the Steward)\
**Status:** Publication and licence mapping adopted; archive implemented with unverified conversion fidelity.\
**Starting revision:** `909f2919716a2c528536fef1dab331b0f0c83f58`

## Charter §9 triggers

- Affects Level 0 parameters? No.
- Affects Level 1 parameters? No.
- Affects success criteria or gate state? No.

G1 and G2 remain OPEN. G3 remains CLOSED (2026-05-01). This is a record of
existing designs, not a build commitment for the next-generation source.
Conversion and catalogue tools belong in `scripts/`; no cavity simulation is
introduced into `src/`.

## Steward authorization and licence adoption

The Steward instructed: “Go, mention AG Schaetz as author, I authorize
publication, you suggest an open license that fits my philosophy, keep
logbook entries for this work”. Publication authorization covers the SHG
package discussed in this thread. It does not identify individual designers
or establish that a drawing matches installed hardware.

The Steward explicitly answered **“Adopt this licence mapping (recommended)”**
to the proposed mapping on 2026-09-14:

| Artifact | Adopted licence |
|---|---|
| Original DWGs, derived DXF and DWG JSON object graphs, drawing exports and previews | CERN-OHL-S-2.0 |
| Catalogue YAML metadata, generated JSON and `docs/_data/shg.yml` | CC-BY-4.0 |
| Catalogue narrative and this logbook entry | CC-BY-SA-4.0 |
| Conversion/generation scripts, schema and tests | MIT |

CERN-OHL-S-2.0 is a hardware-specific reciprocal licence, consistent with
the project's ShareAlike approach while permitting open use, modification
and distribution. It is a new scoped assignment, not a reinterpretation of
the site's MIT “design assets” row. Existing licence assignments elsewhere
are unaffected. Sources: [CERN overview](https://ohwr.org/licences/),
[licence](https://gitlab.com/ohwr/project/cernohl/-/wikis/uploads/819d71bea3458f71fba6cf4fb0f2de6b/cern_ohl_s_v2.txt).

## Agreed acceptance rules

1. Preserve all 28 DWGs byte for byte; record individual and ZIP SHA-256
   hashes. Omit `.DS_Store` and `__MACOSX`. Stable design IDs are independent
   of filenames; preserve original names and archive-name encoding evidence.
2. Extract Guth2021 §2.2.2 geometry before comparisons. Thesis/design matches
   can only support provisional association; confirmation requires bench
   evidence. Source dimensions, inferred geometry and hardware measurements
   remain distinct.
3. Compare ODA and LibreDWG conversion routes on the baseplate, BBO cavity,
   posts/optomechanics assembly, largest assembly and umlaut filename. All
   files still require individual validation despite sharing AC1032 headers.
4. A reference rendering must use an engine independent of the converter.
   Fidelity is unverified when that reference is unavailable. A successful
   parse or a source thumbnail is not a substitute for this check.
5. A qualifying layout has renderable paper-space content beyond viewport
   frames, or an enabled viewport displaying renderable model-space content
   under its clipping/layer settings. Record every layout's disposition.
   Provide a model-space view when substantive geometry has no such layout.
6. A part describes one manufactured component; an assembly depicts multiple
   identifiable components, including flattened geometry. Annotation blocks
   do not establish assembly status. Unresolved classification cannot waive
   the required part DXF export. Record conversion losses and unavailable
   source-side checks explicitly; do not claim fabrication readiness.
7. Preserve source units; normalize extracted numerical fields to SI. Use
   drawing evidence tags `D` (direct), `D*` (ambiguous/inferred), `OPEN`
   (unresolved), separate from hardware-association status. Materials and
   tolerances require source evidence.
8. Canonical YAML and raw/processed data live under `data/designs/shg/`.
   Declare this layout in `data/README.md`, map licences in `LICENSES.md`,
   and generate the new `docs/_data/shg.yml` and downloadable JSON from it.
   Add new schema, checksum, link and generated-data staleness tests.

STEP and interactive 3D are deferred until suitable source models and a
validated route exist. Large export sizes are measured before choosing
storage. Neither a software release nor a Zenodo deposit is part of this
task. The unqualified Zenodo sentence in `CONVENTIONS.md:94` remains a
separate RC-10 inconsistency; it is not corrected here.

## Implementation and validation

The [catalogue](../data/designs/shg/catalogue.yaml) records all 28 originals,
22 parts and 6 assemblies, direct compressed DXF exports, compressed source
reader JSON graphs and 41 qualifying paper layouts. Each has PDF/SVG/PNG
previews, individual hashes, source-side inspection and annotation records.
Raw DWGs are unchanged. The five-file conversion comparison and the
all-file source checks are detailed in the
[conversion work record](2026-09-14-shg-conversion-pilot.md).

The [web catalogue](../docs/components/shg-designs.html) is linked from the
site index, component baseline and photographic survey. It reads generated
site YAML from canonical metadata, offers downloadable JSON plus JSON Schema,
and supports stage/name filtering. Its content remains available without
JavaScript. `data/README.md` and `LICENSES.md` explicitly declare the new
layout and adopted artifact scopes; the new data directory and generated-data
staleness tests are additions to the repository.

The [Guth geometry extraction](../data/literature/Guth2021/geometry.yaml)
adds §2.2.2 values with printed and PDF page references. The local PDF is
not committed. No numerical drawing-to-thesis match has been established.
All 28 hardware associations therefore remain `design_only`.

Publication is permitted with the explicit `unverified` preview label.
An independent CAD rendering, complete native assembly relationships,
engineering-font fidelity, fabrication validation and bench association
remain open. They are acceptance conditions for stronger future claims,
not claims made by this publication. Gate state is unchanged.

Published in commit `bd44419301b5e82e8bc47cadabc3e96e25af84dc` to the existing
`main:/docs` GitHub Pages source. The build completed successfully on
2026-09-14 at 13:44:05 UTC. The
[public catalogue](https://uwarring82.github.io/mg-plus-uv-chain/components/shg-designs.html)
and representative downloads were checked after deployment; details are
in the conversion work record.

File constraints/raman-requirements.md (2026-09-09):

# Raman requirements — `constraints/raman-requirements.md`

**CHARTER §1.5 Level 0** task constraints for ²⁵Mg⁺ Raman / spin–motion control.

**Status:** Phase 0.5 deliverable. **DRAFT — NOT LOCKED.** This document contains a proposed bounded-scenario set (Conservative / Nominal / Aggressive) for Steward review. It does **not** constitute a G3 closure; locking requires the §5.3 gate-closure protocol, a logbook entry, and Integrator acknowledgement.

**Review note — 2026-09-09:** The [repository review (RC-02/03, D2)](../logbook/2026-09-09-repository-review-task-card.md) identified a mismatch between the scattering-rate table and its printed equation; the interpretation of the recorded rates and the numerical corrections remain open.

---

## Draft scenario summary

| Scenario | Δ (GHz) | Ω_R / 2π (kHz) | Γ_sc (s⁻¹) | Gate-time estimate (μs) | Scattering / gate |
|---|---|---|---|---|---|
| **Conservative** | 80 | 100 | 2.5 × 10³ | ~5.0 | ~0.013 |
| **Nominal** | 40 | 400 | 2.0 × 10⁴ | ~1.25 | ~0.025 |
| **Aggressive** | 15¹ | 1 000 | 1.1 × 10⁵ | ~0.50 | ~0.055 |

*Table 1 — Proposed bounded-scenario set. All values are **draft estimates** anchored to order-of-magnitude ²⁵Mg⁺ physics below; Steward must verify against the institutional trap record and Phase 1 literature dossier before locking.*

¹ *See §1.4: conditional on G1 closure narrowing the §8.1 forbidden domain to < 500 MHz width or demonstrating architecture-specific absence.*

---

## 1. Detuning window Δ from ³P₁/₂ and ³P₃/₂

### 1.1 Sign convention

Red-detuned relative to the excited state: Δ > 0 means the laser frequency is **below** the ³S₁/₂ → ³Pⱼ transition frequency (ω_L = ω₀ − Δ).

Both ³P₁/₂ and ³P₃/₂ are used as intermediate levels. The Raman transition involves two beams whose frequency difference matches the ground-state hyperfine / motional splitting. Each beam is detuned from its nearer ³P level by Δ₁ or Δ₂.

### 1.2 Admissible Δ range (draft)

| Boundary | Value | Rationale |
|---|---|---|
| Lower bound | ~10 GHz (~250 × Γ) | Must stay far enough from resonance that spontaneous scattering remains controllable and AC Stark shifts do not destabilise the qubit frequency beyond the compensation range. |
| Upper bound | ~200 GHz | Practical intensity ceiling: at very large Δ the required laser power becomes prohibitive for a given Ω_R (Ω_R ∝ I/Δ). The fine-structure splitting (~2.74 THz) sets a much-higher hard ceiling beyond which two-path interference between ³P₁/₂ and ³P₃/₂ must be modelled explicitly. |

*The Charter v1.0 numeric anchor is “order ~10 GHz to ~100 GHz”; the draft upper bound is extended to ~200 GHz to accommodate the Conservative scenario.*

### 1.3 Forbidden sub-domains

- **14-GHz unlockable resonance domain** (CHARTER §8.1). Until G1 closes, this region is treated as operationally forbidden regardless of architecture choice.
- **Regions where Δ is comparable to the fine-structure splitting** (~2.74 THz) with sign such that one beam is near ³P₁/₂ and the other near ³P₃/₂ — these require explicit two-path Raman analysis and are excluded from the scenario set above.

### 1.4 Scenario detunings

- **Conservative:** Δ = 80 GHz. Large margin against the 14-GHz anomaly; scattering suppressed as 1/Δ².
- **Nominal:** Δ = 40 GHz. Typical of published Mg⁺ Raman sources (Friedenauer 2006 and institutional record).
- **Aggressive:** Δ = 15 GHz. Near the lower practical limit; requires careful scattering budgeting and AC-Stark compensation. **Operational warning:** This is only ~1 GHz from the §8.1 14-GHz forbidden domain. Friedenauer 2006 §4 describes the anomaly as a domain of finite width. The Aggressive scenario is therefore **conditional on G1 closure** demonstrating that the forbidden domain is narrower than ~500 MHz or is architecture-specific and absent in the chosen design.

---

## 2. Target two-photon Rabi frequency Ω_R

### 2.1 Scaling relation

For a Raman transition driven by two beams of equal single-photon Rabi frequency Ω₁ = Ω₂ = Ω through a single intermediate level (or through two levels with comparable detuning):

$$\Omega_R = \frac{\Omega^2}{2\Delta}$$

with

$$\Omega = \frac{|\mathbf{d}_{ge}| \, E_0}{\hbar} = \frac{|\mathbf{d}_{ge}|}{\hbar} \sqrt{\frac{2 I}{c \varepsilon_0}}$$

where $I = P / (\pi w_0^2)$ is the single-beam intensity at the ion for a Gaussian beam of waist $w_0$.

### 2.2 Effective dipole moment (²⁵Mg⁺ placeholder)

From the natural linewidth $\Gamma / 2\pi \approx 41$ MHz (NIST / atomic-data reference; see `src/parameters.py` placeholder):

$$|\mathbf{d}_{ge}|^2 = \frac{3\pi \varepsilon_0 \hbar c^3 \Gamma}{\omega^3}$$

Evaluated at $\lambda \approx 280$ nm this gives $|d_{ge}| \approx 1.6 \times 10^{-29}$ C·m ($\approx 1.9\, e a_0$). This is an **order-of-magnitude estimate** pending Phase 1 atomic-data verification. The actual Raman transition involves Clebsch–Gordan coefficients and interference between ³P₁/₂ and ³P₃/₂ paths; the effective dipole may differ by factors of order unity.

### 2.3 Intensity → Ω_R coupling (draft)

Using the placeholder dipole moment, the single-beam Rabi frequency is approximately

$$\frac{\Omega}{2\pi} \approx 525 \,\text{MHz} \times \sqrt{\frac{P}{\text{mW}}} \times \frac{20\,\mu\text{m}}{w_0}$$

and therefore

$$\frac{\Omega_R}{2\pi} \approx 138 \,\text{MHz} \times \frac{P/\text{mW}}{(w_0 / 20\,\mu\text{m})^2} \times \frac{1}{\Delta / \text{GHz}}$$

*This prefactor is an order-of-magnitude estimate from the single-intermediate-level model; the full multi-level Raman interference (²⁵Mg⁺ ³P₁/₂ and ³P₃/₂ paths, Clebsch–Gordan coefficients) will be implemented in Phase 3 simulation. The tabulated scenario values below are retained as draft estimates pending that verification.*

### 2.4 Scenario Ω_R values

| Scenario | Ω_R / 2π | Derivation sketch |
|---|---|---|
| Conservative | 100 kHz | ~5.0-μs π-pulse; compatible with low heating-rate traps and modest UV power. |
| Nominal | 400 kHz | ~1.25-μs π-pulse; matches typical Mg⁺ gate speeds in the institutional record. |
| Aggressive | 1 000 kHz | ~0.50-μs π-pulse; demands highest UV power and smallest waist, tightest stability. |

---

## 3. Acceptable spontaneous-scattering rate Γ_sc

### 3.1 Scaling relation

For a single intermediate level and two beams of equal intensity:

$$\Gamma_{sc} \approx \frac{\Gamma}{2} \left(\frac{\Omega}{2\Delta}\right)^2 \times 2 = \Gamma \left(\frac{\Omega}{2\Delta}\right)^2$$

Using $\Omega_R = \Omega^2/(2\Delta)$, this becomes

$$\Gamma_{sc} \approx \frac{\Gamma \, \Omega_R}{2\Delta}$$

### 3.2 Scenario Γ_sc values (derived, not independent)

| Scenario | Γ_sc (s⁻¹) | Scattering events / π-pulse | Comment |
|---|---|---|---|
| Conservative | 2.5 × 10³ | ~0.013 | Low single-percent scattering probability in the draft single-level estimate. |
| Nominal | 2.0 × 10⁴ | ~0.025 | Few-percent scattering probability; must be checked against the full gate-error budget. |
| Aggressive | 1.1 × 10⁵ | ~0.055 | Approaching the practical limit; requires error-model justification or shorter gates. |

*These are derived from the (Ω_R, Δ) pairs above using the scaling relation with Γ / 2π = 41 MHz. They are **not** independent choices — if Ω_R or Δ is revised, Γ_sc must be recomputed.*

### 3.3 Per-gate scattering budget

For a gate of duration τ_gate = π/Ω_R, where Ω_R is an angular frequency:

$$N_{sc} = \Gamma_{sc} \, \tau_{gate} = \frac{\pi \Gamma}{2\Delta}$$

Remarkably, $N_{sc}$ depends **only on Δ** (for the single-intermediate-level model). Using the draft table values above, Δ = 40 GHz gives $N_{sc} \approx 0.025$ and Δ = 80 GHz gives $N_{sc} \approx 0.013$.

*This independence breaks down when two ³P paths interfere, when polarisation selection rules suppress one path, or when the gate is not a simple π-pulse. Phase 3 simulation must use the full multi-level model.*

---

## 4. Beam geometry at the ion

### 4.1 Beam waist

| Scenario | Waist w₀ (μm) | Comment |
|---|---|---|
| Conservative | 30 | Large waist relaxes alignment and astigmatism tolerances; higher power required for same Ω_R. |
| Nominal | 20 | Typical of the existing trap geometry. |
| Aggressive | 12 | Tight focus for peak intensity; demands M² < 1.2 and stable pointing. |

### 4.2 Propagation directions and k-vector projections

The Raman beam pair is assumed to propagate at an angle θ_Raman relative to each other, with a component of $\Delta \mathbf{k}$ along the trap axis of interest (typically the axial mode). The exact geometry is trap-specific and does **not** belong in the source-side constraint file; it is recorded here as a placeholder pending trap-side coordination.

- **Draft assumption:** counter-propagating geometry (θ_Raman ≈ 180°) for maximum $\Delta k$ and strongest Lamb–Dicke coupling.
- **k-vector projection onto motional modes:** to be specified in coordination with the trap apparatus (outside this Charter’s scope per §3 non-goals).

### 4.3 Polarisation requirements

- σ⁺/σ⁻ or π/σ combinations depending on the chosen Raman transition (e.g. |F=3, m_F=+1⟩ ↔ |F=2, m_F=+1⟩ via σ⁺/σ⁻ or similar).
- Polarisation purity > 100:1 to suppress off-resonant coupling to unwanted Zeeman sub-levels.
- Polarisation drift envelope: < 5 % relative over an 8-h operation (couples to `phase-noise-budget.md`).

---

## 5. Reference triple and bounded-scenario set

### 5.1 Reference triple (draft — for Phase 4 anchoring)

Per CHARTER §5.2, Phase 4 scoring must be computed at minimum on a reference triple. The **Nominal** scenario is proposed as the reference:

| Parameter | Value |
|---|---|
| Δ_ref | 40 GHz (red-detuned from nearer ³P level) |
| Ω_R,ref / 2π | 400 kHz |
| Γ_sc,ref | 2.0 × 10⁴ s⁻¹ |

*Steward to confirm or replace before G3 closure.*

### 5.2 Bounded-scenario set (fallback)

If the Steward decides that precise envelopes cannot be locked, the full C/N/A table above serves as the bounded-scenario set per CHARTER §1.5 stall mitigation. Phase 4 scoring would then run:

1. **At minimum** on the Conservative scenario (mandatory per v0.9 Integrator insertion).
2. Optionally on Nominal and Aggressive as sensitivity tests.

---

## 6. Locking protocol

**This document is NOT locked.**

Before G3 closure, the following must occur:

1. Steward review of the C/N/A numbers against the institutional trap record and Phase 1 literature.
2. Verification of the effective dipole moment and multi-level Raman prefactor (see §2.2).
3. Confirmation of beam-geometry placeholders against the trap apparatus.
4. Population of `src/parameters.py` with the agreed reference triple or Conservative scenario.
5. Filing of the G3 gate-closure logbook entry per `/logbook/_templates/gate-closure.md`.
6. Integrator acknowledgement of the G3 closure entry.

After locking, this document and the populated `parameters.py` become subject to CHARTER §9 asymmetric erosion protection: tightening is permitted with rationale; relaxation requires Council-3 + Integrator deliberation.

---

## 7. Open items / literature anchors needed

- [ ] **Atomic data:** Confirm |d_ge|, Γ, and isotope shifts for ²⁵Mg⁺ from NIST ASD or peer-reviewed compilation.
- [ ] **Multi-level Raman prefactor:** The single-intermediate-level model used here is a simplification. The actual Ω_R and Γ_sc involve two ³P paths (fine-structure splitting ~2.74 THz) with opposite detuning signs. Derive the full expression and update the scaling relations.
- [ ] **AC Stark shift:** At Δ = 15 GHz (Aggressive), quantify the differential AC Stark shift of the qubit states and verify it lies within the compensation range.
- [ ] **14-GHz anomaly:** Until G1 closes, the forbidden domain near 14 GHz is treated as absolute. Revisit after G1 attribution if the mechanism suggests the anomaly is architecture-specific.
- [ ] **Trap geometry:** Confirm beam waist, propagation angle, and k-vector projection with the trap-side team.

---

## References

- CHARTER §1.5, §2, §5 Phase 0.5 row, §5.1 G3, §5.2 reference-triple anchoring, §8.1, §9 erosion protection.
- CONVENTIONS §1 (SI units; `parameters.py` contract layer).
- `src/parameters.py` — placeholder atomic data and G3 lock helpers.
- Background literature: `/docs/KD-2026-XXX-uv-280nm.md` (Phase 1 dossier; to be created).

---

*Document version: DRAFT 0.1 — 2026-05-01. Not for locking.*

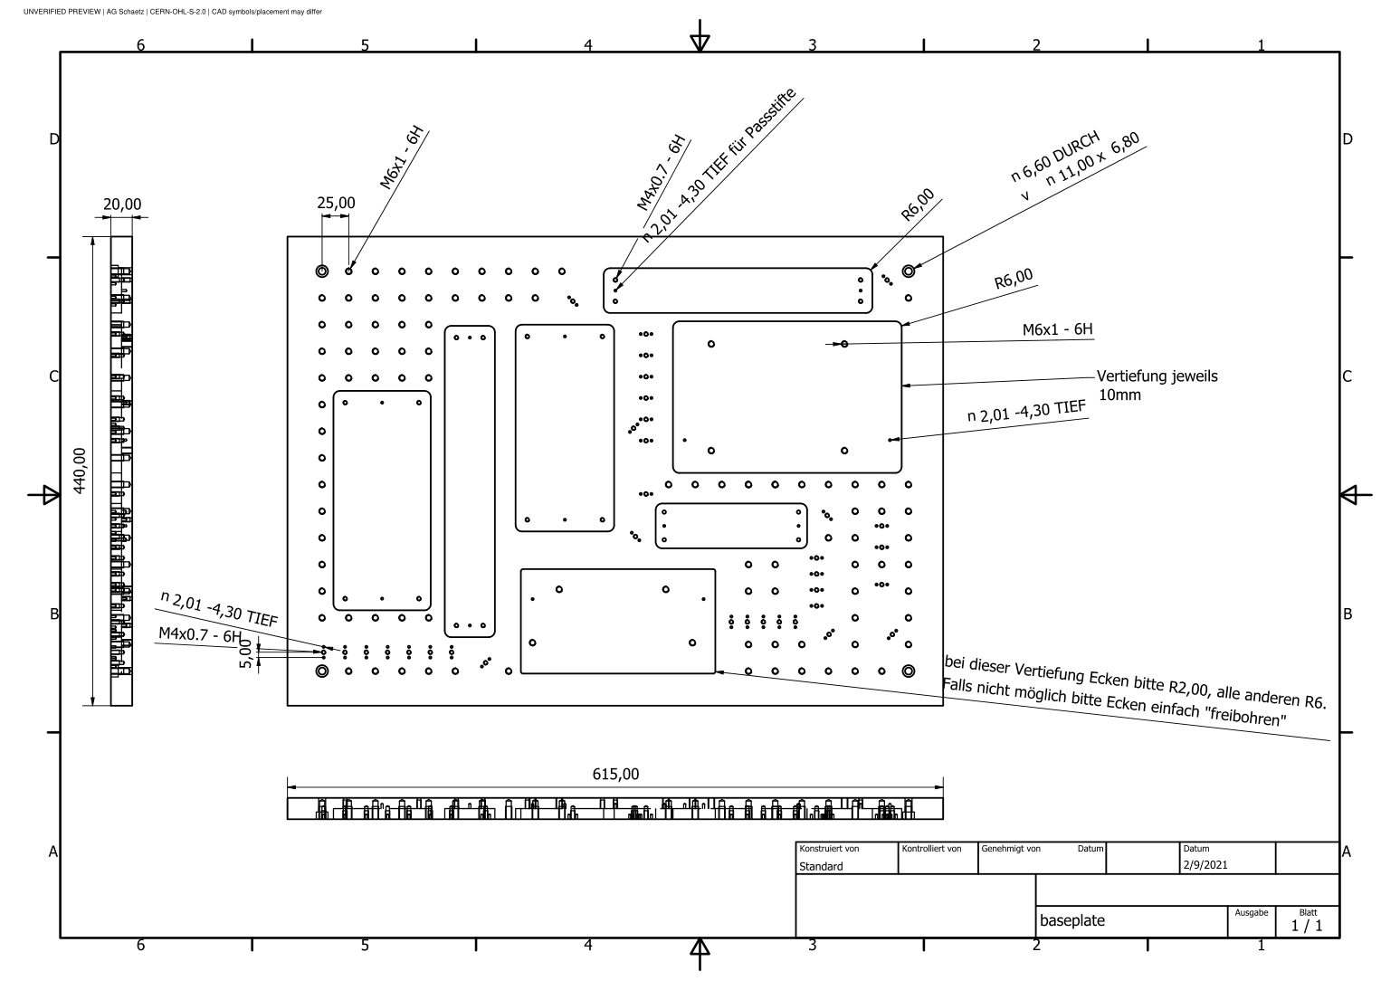
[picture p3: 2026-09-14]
docs/assets/shg/SHG-001/sheet-01.png

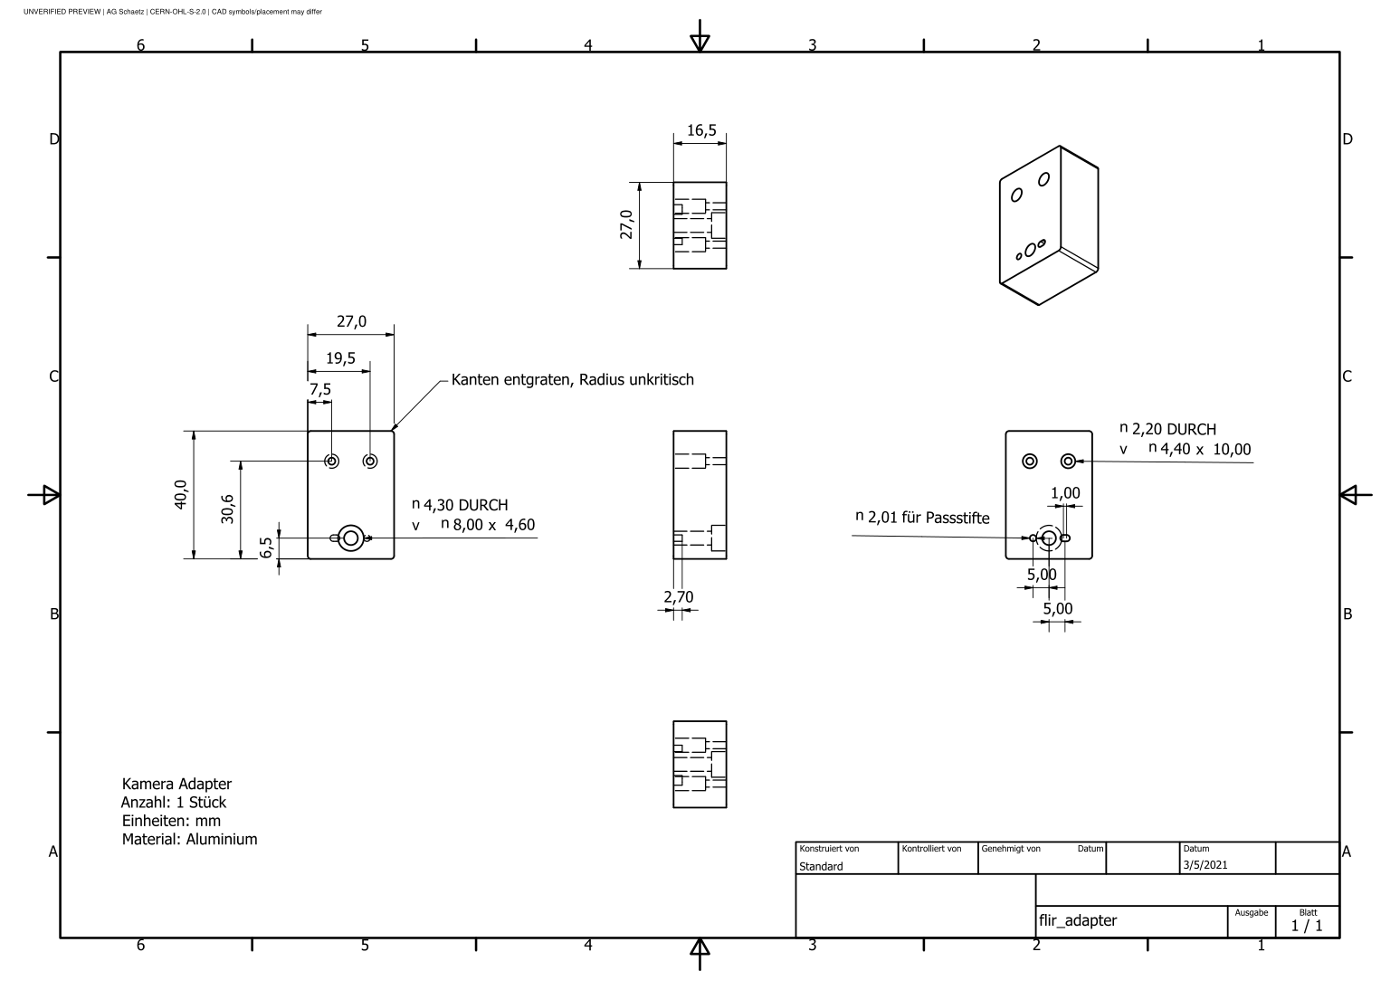
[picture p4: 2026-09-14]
docs/assets/shg/SHG-016/sheet-01.png

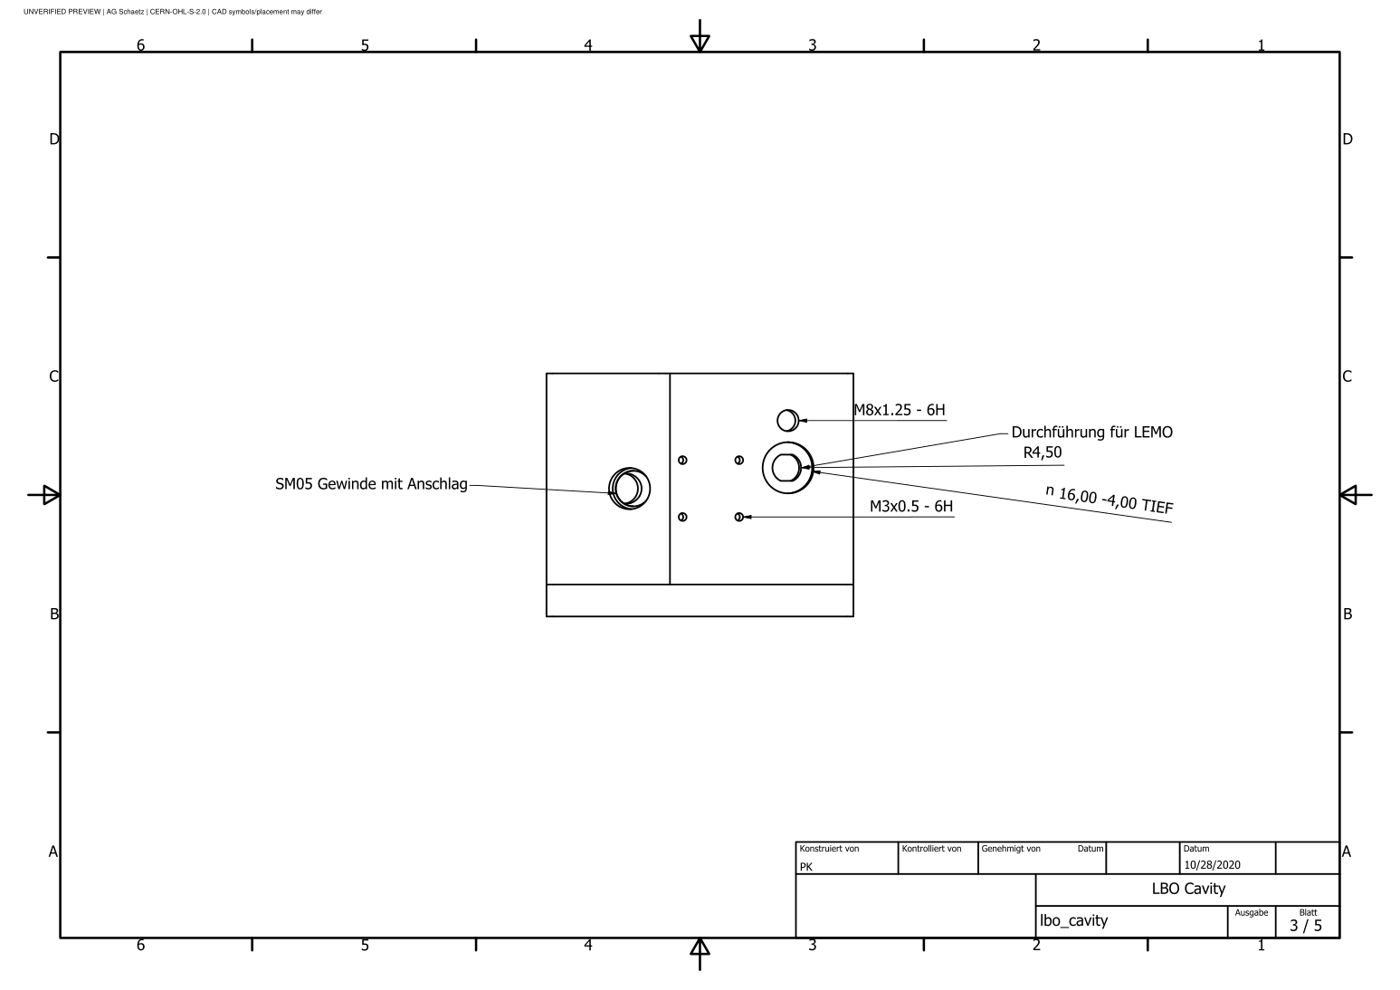
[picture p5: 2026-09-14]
docs/assets/shg/SHG-020/sheet-03.png

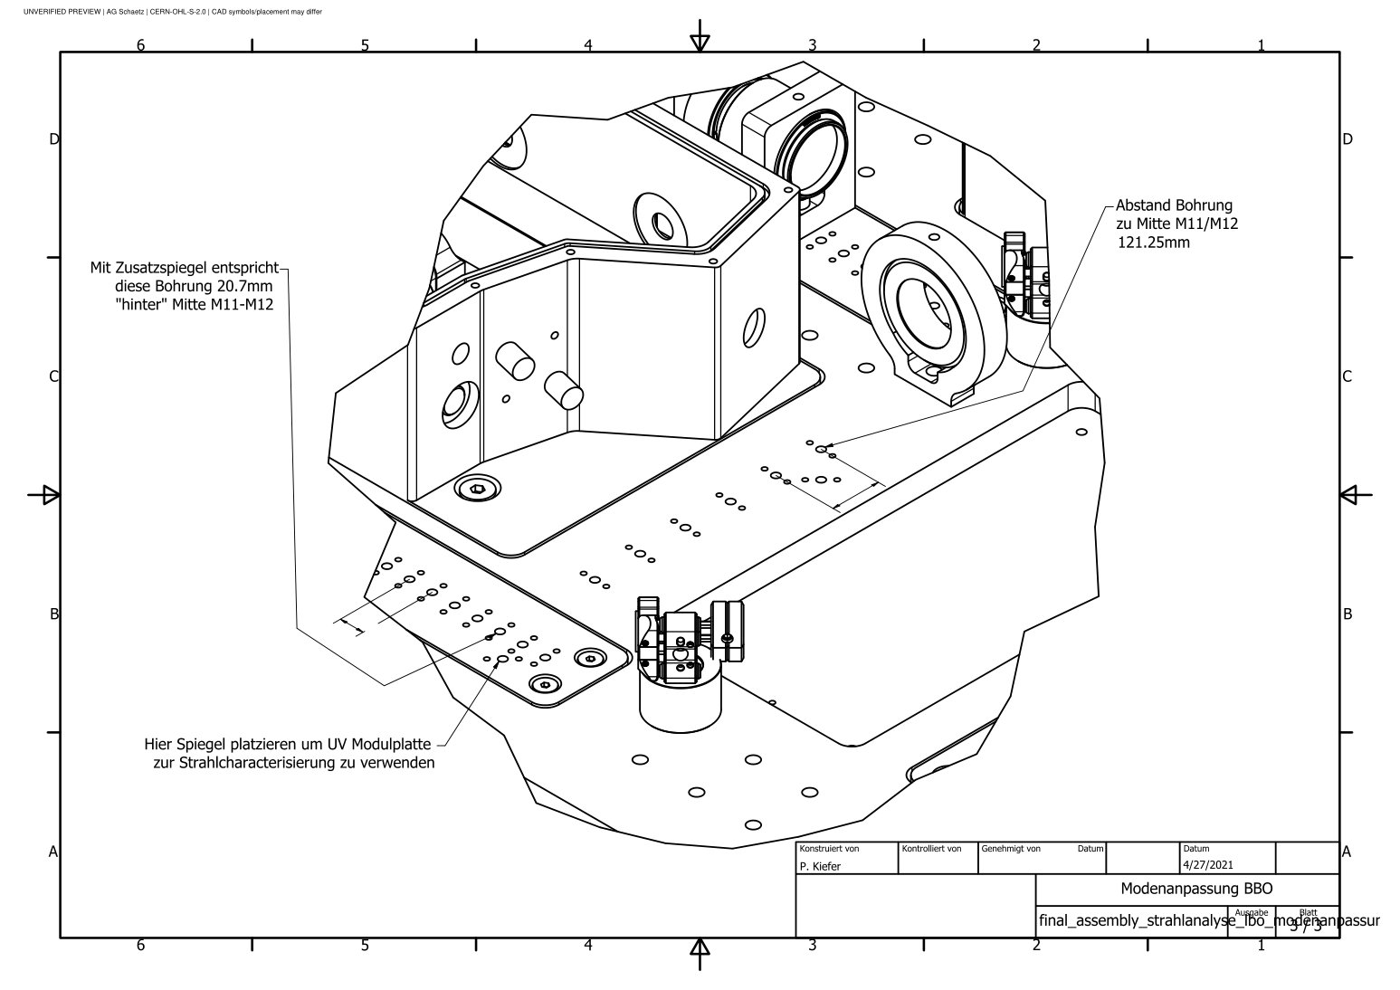
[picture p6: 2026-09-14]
docs/assets/shg/SHG-015/sheet-03.png

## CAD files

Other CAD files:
data/designs/shg/raw/SHG-010.dwg
data/designs/shg/raw/SHG-022.dwg
data/designs/shg/raw/SHG-006.dwg
data/designs/shg/raw/SHG-002.dwg
data/designs/shg/raw/SHG-023.dwg
data/designs/shg/raw/SHG-017.dwg
data/designs/shg/raw/SHG-011.dwg
data/designs/shg/raw/SHG-001.dwg
data/designs/shg/raw/SHG-024.dwg
data/designs/shg/raw/SHG-012.dwg
data/designs/shg/raw/SHG-027.dwg
data/designs/shg/raw/SHG-008.dwg
data/designs/shg/raw/SHG-021.dwg
data/designs/shg/raw/SHG-016.dwg
data/designs/shg/raw/SHG-020.dwg
data/designs/shg/raw/SHG-013.dwg
data/designs/shg/raw/SHG-019.dwg
data/designs/shg/raw/SHG-003.dwg
data/designs/shg/raw/SHG-004.dwg
data/designs/shg/raw/SHG-005.dwg
data/designs/shg/raw/SHG-007.dwg
data/designs/shg/raw/SHG-009.dwg
data/designs/shg/raw/SHG-014.dwg
data/designs/shg/raw/SHG-018.dwg
data/designs/shg/raw/SHG-025.dwg
data/designs/shg/raw/SHG-026.dwg
data/designs/shg/raw/SHG-028.dwg

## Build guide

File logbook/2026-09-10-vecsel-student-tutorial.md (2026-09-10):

# VECSEL student notebook: principles and frequency noise

**Date:** 2026-09-10\
**Steward:** Ulrich Warring\
**Status:** Teaching notebook implemented; local and fresh-runtime checks pass.\
**Starting revision:** `1ffe916383179f4cf02e1d497d936968f752c0c5`

## Charter §9 triggers

- Affects Level 0 parameters? No.
- Affects Level 1 parameters? No.
- Affects success criteria or gate state? No.

## Teaching scope

[Tutorial 5](../docs/tutorials/05-vecsel-principles-noise.html) provides a
standalone VECSEL introduction with five original figures and saved parameter
overrides. Students can read it on Pages, download the executed notebook or
open it in Colab from the [student guide](../docs/tutorials/index.md).

The lesson covers the gain mirror (pump, quantum wells, standing-wave overlap,
DBR and thermal contact), external-cavity feedback, ideal birefringent and
etalon filters, fixed-mode path-length sensitivity, and technical frequency
noise from mechanics, temperature, pump power and actuator electronics.
A synthetic PSD budget leads to field coherence and the special white-noise
Lorentzian linewidth limit. Exercises connect changes in components and noise
to the plots, then ask what measurements could replace the teaching inputs.

**Pre-G1, exploratory, not promoted.** The wavelength illustrates the magnesium
seed band. Other numerical inputs are chosen examples, not measurements or
accepted hardware specifications. The notebook derives ideal filter and
coherence relations and cites Burd 2016/2023, Lee–Moriya–Hastie 2023 and
Di Domenico–Schilt–Thomann 2010. It does not simulate semiconductor growth,
solve mode competition or predict this laboratory's linewidth.

The noise conventions are explicit: one-sided PSD, ordinary Fourier frequency,
complex transfer functions, independent-input PSD addition, and coherent
addition of the thermal and fast paths driven by the same pump fluctuation.
The white floor is illustrative, not an inferred fundamental linewidth.
Integrated RMS frequency variation is not labelled FWHM. Colored-noise
coherence uses a stated 1 Hz–1 MHz integration band.

The companion [VECSEL narrative](../docs/tutorials/vecsel-systems.md) now
separates laser-frequency feedback from a following SHG-cavity lock. The
latter suppresses relative detuning, not absolute seed noise. An 18 kHz
historical actuator scale does not determine linewidth or UV RIN. Related
Henry-factor and path-length statements are narrowed to their assumptions;
historical in-house measurement values retain their evidence labels.

**RC-04 traceability:** commit `480428b` partially addresses
[RC-04](2026-09-09-repository-review-task-card.md#rc-04--next--repair-phase-noise-and-servo-interpretations)
in `vecsel-systems.md`: linewidth/PSD definitions and the following-cavity
servo interpretation now have explicit assumptions and worked examples.
`phase-noise-budget.md`, `friedenauer-baseline.md` and `bc-g-results.md` were
untouched by that commit. The four-document claim audit, harmonic-phase and
path-length checks, and measurement-dependent conclusions remain open;
this is partial progress, not RC-04 acceptance.

## Runtime and provenance

The fifth notebook retains the existing shared-code pin `3466c32`. Its new
teaching inputs and formulas are embedded in the notebook, so the older
checkout need only supply existing shared code and installation metadata.
No new YAML file or uncommitted module is required by an isolated copy.
The four earlier source files and eight rendered outputs remain unchanged.
All five pins agree; RC-06 now says “all tutorial pins” rather than “four”.
Pin freshness enforcement remains planned, with Ulrich accountable.

The renderer accepts a source-level description so the new page carries its
exploratory status instead of the default architecture-neutral description.
The opt-in Colab checker accepts `--stem 05` and verifies inline parameter
inputs as well as the earlier YAML loaders. It remains outside the core test
suite. The manifest generator handles a tutorial absent from its historical
baseline using null before-fields and accepts a selected tutorial/environment.

[The new manifest](../data/review/2026-09-10/vecsel-tutorial-manifest.json)
records exact source/tool/input and output hashes and printed results.
[The environment record](../data/review/2026-09-10/vecsel-environment.txt)
records Python 3.13.7, NumPy 2.5.3, SciPy 1.18.1, Matplotlib 3.11.1 and the
resolved rendering tools. A fresh temporary environment was used after reads
of packages in the existing `.venv` stalled; that environment was not modified.
The RC-07 manifest is refreshed solely for its recorded renderer hash; its
numerical results and rendered analysis outputs remain unchanged.

## Validation

- All lesson cells and embedded checks pass: unit/periodic filter transmission,
  exact-versus-linear resonance shift, ideal feedback identity, zero-delay
  coherence and an independent white-noise integral limit.
- The five figure outputs were visually inspected. Notebook and HTML outputs
  are byte-identical on a second render.
- Black, isort and Ruff pass on the new notebook and changed Python tools.
  Edited tutorial front matter and local Markdown links validate.
- The published notebook has **19 cells: 10 code and 9 Markdown**; all ten
  code cells have execution counts. The fresh-runtime checker appends one
  validation code cell, so its reported **20 cells** describes the augmented
  check notebook. That extra cell verifies the imported module location,
  pinned Git revision and saved pump-noise parameter override. The check
  passes outside any checkout; all five PNGs exactly match the local render.
  Two preliminary attempts encountered GitHub connection resets (HTTP/2 and
  a process-local HTTP/1.1 retry). The successful run uses the normal command
  and unchanged bootstrap; no persistent Git configuration was changed.
- No `src/` or core-test changes. The core suite was not rerun for this
  teaching-only addition. No gate acceptance or replacement specification
  is implied.

Reproduce from the repository root with notebook dependencies installed:

```sh
python scripts/render_tutorials.py 05
python scripts/check_colab_tutorials.py --stem 05
python -m scripts.review.tutorial_manifest --stem 05 --environment data/review/2026-09-10/vecsel-environment.txt > data/review/2026-09-10/vecsel-tutorial-manifest.json
python -m scripts.review.rc07_manifest > data/review/2026-09-10/manifest.json
```

The isolated check exercises fetching the pin, installing dependencies and
executing with saved parameter overrides. It is not a claim of execution
inside Google's hosted service or a signed-in Colab UI.

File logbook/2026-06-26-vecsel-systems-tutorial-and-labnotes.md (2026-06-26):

# VECSEL systems tutorial; in-house Evernote lab-note extraction

**Steward:** Ulrich Warring
**Date:** 2026-06-26
**Status:** NEW PEDAGOGICAL ARTEFACT + LOCAL-DATA EXTRACTION. A new tutorial [`docs/tutorials/vecsel-systems.md`](../docs/tutorials/vecsel-systems.md) explains the in-house VECSEL seed lasers — gain properties, intracavity filtering, and the parameter sensitivities that set the linewidth — for the **~1120 nm → 280 nm** (cooling/detection/Raman) and **~1140 nm → 285 nm** (photoionisation) systems. Two Evernote lab notes were converted ENEX → Markdown into a new `data/lab notes/` category and used to source the tutorial's in-house numbers. No architecture-family-specific code; no binding parameter changed; no gate advanced.

## Header (CHARTER §9 trigger questions)

- **Affects Level 0 parameter?** no — the §1.5 Level 0 row and the G3 reference triple `{Δ_ref = 40 GHz, Ω_R/2π = 400 kHz, Γ_sc = 2.0 × 10⁴ s⁻¹}` are untouched.
- **Affects Level 1 parameter?** no — the tutorial *reports* in-house **measured** device values (étalon FSR ≈ 73 GHz / ≈ 70 GHz, BRF Brewster 57.15°, cavity 127.5 mm, 1.5 % output coupler, PZT ≈ 100 MHz/V, and the VECSEL #2 frequency-noise budget). These are descriptions of existing hardware, not a tightening or relaxation of any Level 1 row. The seed-laser linewidth budget (target ≤ 100 kHz; Friedenauer-parity floor ≈ 200 kHz; stretch ceiling 50 kHz) recorded in [2026-05-08](2026-05-08-vecsel-seed-lasers.md) is unchanged.
- **Affects success criterion?** no.

No Council-3 deliberation required. Tightening-vs-relaxation note: nothing here is a parameter change in either direction; it is documentation plus local-data filing.

## Anti-seeding boundary

The tutorial is pedagogical material over published in-house and external literature; it adds no `/src/` code and no architecture preset. The lab-note extractions live under `data/lab notes/` — a new **local-data** category, sibling to `data/literature/` — not in `/src/`. All of this is admissible pre-G1. **G1 / G2 / G3 status:** G3 closed (2026-05-01); G1 and G2 remain open; nothing in this entry touches them (in particular, UV-degradation / G2 is independent of the seed-laser layer).

## Coastline / Sail

The tutorial labels its sections explicitly: *Coastline* for testable, literature-anchored constraints (gain-medium properties, the filter free spectral ranges, the linewidth criterion) and *Sail* for build-dependent guidance (the 1141 nm "Heidi" system, whose full characterisation is not yet extracted).

---

## 1 · The tutorial

- New page [`docs/tutorials/vecsel-systems.md`](../docs/tutorials/vecsel-systems.md) built around three pillars (steward direction): **gain properties** (resonant-periodic-gain quantum wells, class-A dynamics, gain-peak temperature sensitivity, Henry α), **intracavity filtering** (the BRF / YAG-étalon / PZT hierarchy as a *product-of-losses* mode selection), and **parameter sensitivities → linewidth**.
- Two SVG figures (the project's first content figures): the nested filter / mode-selection hierarchy and the frequency → amplitude-noise conversion chain, both on the site palette.
- The tutorials index was restructured into two tracks (seed-laser systems + SHG enhancement-cavity numerics); the [seed-lasers components page](../docs/components/seed-lasers.md) gained a cross-link.
- A newcomer pass added: learning-objectives box, key-terms glossary, inline glosses, scale callouts, and a "what this proves / does not prove" box.

## 2 · In-house lab-note extraction (ENEX → Markdown)

Two Evernote notes were exported to ENEX and converted to Markdown with a streaming converter (extracts the note body, converts tables/formatting, decodes the embedded `en-media` attachments):

| Note | In-repo Markdown | Source / attachments |
|---|---|---|
| `2021-07 VECSEL project summary` | [`data/lab notes/2021-07-vecsel-project-summary.md`](../data/lab%20notes/2021-07-vecsel-project-summary.md) | fleet #1–#5, assembly/optical-element detail, the **VECSEL #2 frequency-noise budget** |
| `2020-11 VECSEL #2 "Heidi"` (operational diary) | [`data/lab notes/2020-11-vecsel-2-heidi.md`](../data/lab%20notes/2020-11-vecsel-2-heidi.md) | day-by-day operations log for the 1140 nm unit |

**Data-handling policy (new precedent).** The converted Markdown **text** is committed; the binary attachments (102 + 138 images, vendor PDFs) and the source `.enex` files are kept **local-only** via `.gitignore` (`/data/lab notes/*.enex`, `/data/lab notes/*.attachments/`) — the same local-only treatment as `/outreach/`.

**Redaction.** Because the repository is public ([2026-06-26 publication event](2026-06-26-repo-public-and-pages.md)), the "Heidi" operational diary was redacted before commit: lab-internal IP address, internal hostname, and TEC/PID controller register dumps removed; the engineering narrative (diary, observations, target frequencies, the "PID parameters not active — only GAIN" insight) retained.

**Provenance.** Every in-house number folded into the tutorial links back to the 2021-summary Markdown, so the reader can trace each value to its source note. The two earlier Evernote share-links were removed from the tutorial in favour of these in-repo extractions.

## 3 · Rigor revisions (reviewer-driven)

- **Linewidth criterion reframed** from an inequality (`Δν_seed ≪ 18 kHz`) to a **transfer-function** statement: the resonant SHG cavities respond to the residual frequency-noise spectral density *above* the ~18 kHz doubling-cavity lock bandwidth, not to the integrated linewidth. A below/above lock-bandwidth error in the figure and SVG was corrected (the lock *tracks out* sub-bandwidth noise; the *above*-bandwidth residual converts to amplitude noise).
- **Spanke 2025** 101(8) kHz is no longer presented as a proven sub-100 kHz result — it is consistent with the ≤ 100 kHz target but not below it without a delayed self-heterodyne / beat-note measurement.
- **Evidence labels** (`[in-house]`, `[external]`, `[analogue]`, `[inferred]`, `[open]`) added so in-house Heidi data are never silently blended with the Burd 2016 analogue.
- **`docs/references.md` corrected** — Burd 2016: 1117 nm IC = **I-cavity, externally frequency-quadrupled**; 1141 nm VC = **V-cavity, intracavity-doubled to 571 nm** then externally doubled to 285 nm (the prior entry had the topologies reversed).
- **Consistency pass on [`docs/components/seed-lasers.md`](../docs/components/seed-lasers.md)** — its linewidth section and RIN open-item were brought into line with the §3.4 transfer-function framing (frequency-noise PSD above the lock bandwidth is the input budget; UV RIN is the downstream observable; integrated linewidth is only a proxy). The tutorial tuning table was also corrected against the [Span25] extraction (PZT ~1 GHz travel; étalon ~10 GHz before mode hop, distinct from the ≈73 GHz FSR peak spacing), and the 1141 nm summary row updated to "in use (Heidi)".

## 4 · What is *not* in this entry / open items

- **RIN at the SHG lock bandwidth** — the binding figure of merit of §3.4 — is still unmeasured for the in-house build.
- **In-house 1140 nm ("Heidi")** linewidth, output power, and 285 nm conversion route are not yet extracted (the relevant cells in the tutorial are tagged `[open]`).
- **A true sub-100 kHz intrinsic linewidth** has not been demonstrated (measurement-method-limited).
- The Evernote **attachments remain local-only**; only the redacted Markdown text is public.

## See also

- [Tutorial — VECSEL systems (1118 nm and 1141 nm)](../docs/tutorials/vecsel-systems.md)
- [Components — Seed lasers (VECSEL)](../docs/components/seed-lasers.md) · [2026-05-08 steward direction](2026-05-08-vecsel-seed-lasers.md)
- [References — Burd 2016 / 2023, Kiefer/Guth/Spanke lineage](../docs/references.md)
- [2026-06-26 — repository made public; Pages enabled](2026-06-26-repo-public-and-pages.md)

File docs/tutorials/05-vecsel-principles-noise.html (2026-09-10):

--- layout: notebook title: "Tutorial 5 — Inside a VECSEL: chip, cavity, filters and frequency noise" description: Tutorial notebook (05-vecsel-principles-noise). VECSEL models; pre-G1, exploratory, not promoted. ---

In [1]:

# SPDX-License-Identifier: MIT

# Tutorial 5 — Inside a VECSEL: chip, cavity, filters and frequency noise¶

Pre-G1, exploratory, not promoted. These are teaching models, not a simulation or linewidth prediction for an accepted laboratory design. You need basic waves, optical power and Python arrays; no semiconductor device simulation experience is assumed.

Open in Colab (https://colab.research.google.com/github/uwarring82/mg-plus-uv-chain/blob/main/docs/tutorials/05-vecsel-principles-noise.ipynb). Save a copy to Drive, use a CPU runtime and run all cells. Setup fetches reviewed shared code when no checkout exists. All new example parameters live in this notebook, so an isolated copy contains its teaching inputs. Edit the experiment cell to preserve changes with your saved notebook. Student guide (https://uwarring82.github.io/mg-plus-uv-chain/tutorials/).

In [2]:

from __future__ import annotations

import os
import subprocess
import sys
import tempfile
from pathlib import Path

# A local checkout uses its own code. Colab starts without a checkout, so
# fetch a fixed reviewed revision into a temporary runtime directory.
REFERENCE_REVISION = "3466c3262aa72af93f10a3699c48782d401548f8"
REPO_ROOT = Path.cwd().resolve()
while not (REPO_ROOT / "src" / "enhancement_cavity.py").is_file():
    if REPO_ROOT == REPO_ROOT.parent:
        break
    REPO_ROOT = REPO_ROOT.parent
if not (REPO_ROOT / "src" / "enhancement_cavity.py").is_file():
    REPO_ROOT = Path(tempfile.mkdtemp(prefix="mg-uv-tutorial-"))
    subprocess.run(
        [
            "git",
            "clone",
            "--quiet",
            "https://github.com/uwarring82/mg-plus-uv-chain.git",
            str(REPO_ROOT),
        ],
        check=True,
    )
    subprocess.run(
        ["git", "-C", str(REPO_ROOT), "checkout", "--quiet", REFERENCE_REVISION],
        check=True,
    )
    subprocess.run(
        [sys.executable, "-m", "pip", "install", "--quiet", "-e", str(REPO_ROOT)],
        check=True,
    )
    os.chdir(REPO_ROOT)
    print("Runtime code and inputs:", REFERENCE_REVISION)
sys.path.insert(0, str(REPO_ROOT))

import matplotlib.pyplot as plt  # noqa: E402
import numpy as np  # noqa: E402
from matplotlib.patches import Arc, Rectangle  # noqa: E402
from scipy.integrate import trapezoid  # noqa: E402

from src.parameters import SPEED_OF_LIGHT_m_per_s as c  # noqa: E402

## Your experiment¶

The default wavelength illustrates the magnesium seed band. Every other numerical value below is a chosen teaching input, not a measured device parameter. Geometry is inspired by the linear-cavity topology in Burd et al. (2023), Sec. 2 and Fig. 2 (https://tf.nist.gov/general/pdf/3090.pdf), which describes different wavelengths. No measured linewidth is imported.

Try {"noise": {"pump_rin_asd_per_sqrtHz": 2e-7}} to reduce pump amplitude spectral density tenfold. Use {} to restore the defaults. Run this cell and the cells below it again after an edit.

In [3]:

parameter_overrides = {}

In [4]:

params = {
    "optics": {
        "wavelength_m": 1118e-9,
        "optical_length_m": 0.125,
        "brf_thickness_m": 0.003,
        "brf_delta_n": 0.009,
        "etalon_thickness_m": 0.001,
        "etalon_group_index": 1.82,
        "etalon_reflectivity": 0.60,
        "etalon_detuning_Hz": 0.0,
    },
    "noise": {
        "length_asd_m_per_sqrtHz": 3e-14,
        "temperature_asd_K_per_sqrtHz": 2e-6,
        "thermal_tuning_Hz_per_K": 5e7,
        "pump_power_W": 10.0,
        "pump_rin_asd_per_sqrtHz": 2e-6,
        "pump_thermal_Hz_per_W": 2e6,
        "pump_fast_Hz_per_W": 2e5,
        "driver_asd_V_per_sqrtHz": 1e-6,
        "pzt_tuning_Hz_per_V": 1e8,
        "white_frequency_psd_Hz2_per_Hz": 1e3,
        "servo_bandwidth_Hz": 1e4,
    },
}
for section, changes in parameter_overrides.items():
    if section not in params or not isinstance(changes, dict):
        raise ValueError("Use a dictionary under 'optics' or 'noise'.")
    if changes.keys() - params[section].keys():
        raise KeyError(f"Unknown parameters in {section}")
    params[section].update(changes)
o, n = params["optics"], params["noise"]
assert all(v > 0 for k, v in o.items() if k != "etalon_detuning_Hz")
assert 0 < o["etalon_reflectivity"] < 1
assert all(v >= 0 for v in n.values()) and n["servo_bandwidth_Hz"] > 0
nu0 = c / o["wavelength_m"]
fsr_cavity = c / (2 * o["optical_length_m"])
fsr_etalon = c / (2 * o["etalon_group_index"] * o["etalon_thickness_m"])
fsr_brf = c / (o["brf_delta_n"] * o["brf_thickness_m"])
print("Illustrative FSRs, not measured hardware values:")
print(f"  cavity {fsr_cavity / 1e9:.6f} GHz; etalon {fsr_etalon / 1e9:.6f} GHz")
print(f"  ideal one-plate BRF {fsr_brf / 1e12:.6f} THz")

Illustrative FSRs, not measured hardware values:
  cavity 1.199170 GHz; etalon 82.360565 GHz
  ideal one-plate BRF 11.103424 THz

## 1. The chip supplies gain; the external cavity supplies feedback¶

An optical pump creates carriers in the semiconductor barriers. Carriers relax into quantum wells, where stimulated emission amplifies the resonant field. A distributed Bragg reflector (DBR) supplies feedback. Placing wells near standing-wave antinodes improves overlap: this is resonant periodic gain. A thermal contact and heat spreader carry pump-deposited heat away. The layer order and heat-spreader placement vary between chip designs. Burd et al. (2023), Sec. 2 (https://tf.nist.gov/general/pdf/3090.pdf).

The schematic is an original conceptual drawing, not a fabrication recipe. A long external cavity can give a photon lifetime longer than the carrier lifetime (class-A dynamics). This condition can suppress relaxation oscillations; it does not remove technical noise or establish a linewidth.

In [5]:

fig, (ax, chip) = plt.subplots(1, 2, figsize=(12, 4.5), width_ratios=[1.8, 1])
ax.set(xlim=(0, 11), ylim=(-1.7, 2.3), title="Linear VECSEL: functional layout")
ax.axis("off")
ax.add_patch(Rectangle((1, -0.45), 0.22, 0.9, color="#245b78"))
ax.annotate(
    "", (9.1, 0), (1.3, 0), arrowprops=dict(arrowstyle="<->", lw=2, color="#b64239")
)
for x, label, color in [
    (4, "BRF / Lyot\npolarization\ncoarse tuning", "#d69b38"),
    (6.4, "Etalon\nperiodic\ntransmission", "#6c8d56"),
]:
    ax.add_patch(Rectangle((x, -0.4), 0.22, 0.8, angle=-12, color=color))
    ax.text(x, -0.65, label, ha="center", va="top", fontsize=9)
ax.add_patch(Arc((9.25, 0), 0.5, 1.1, theta1=110, theta2=250, lw=3, color="#245b78"))
ax.text(9.2, 0.8, "Output coupler\non PZT", ha="center", fontsize=10)
ax.annotate(
    "output",
    (10.8, 0),
    (9.5, 0),
    arrowprops=dict(arrowstyle="->", color="#b64239"),
    va="center",
)
ax.annotate(
    "pump",
    (1.2, 0.1),
    (2.5, 1.5),
    arrowprops=dict(arrowstyle="->", color="#8643a0", lw=3),
    ha="center",
)
ax.text(1.1, -0.8, "Gain\nmirror", ha="center")
ax.text(
    5.5,
    1.75,
    "Filters shape relative round-trip loss; gain competition also matters",
    ha="center",
    fontsize=9,
)
chip.set(xlim=(0, 3.6), ylim=(0, 4.1), title="Gain mirror: not to scale")
chip.axis("off")
chip.add_patch(Rectangle((0.2, 0.15), 2.4, 0.5, color="#9fa9af"))
chip.text(1.4, 0.4, "thermal contact", ha="center", va="center", fontsize=9)
for i in range(8):
    chip.add_patch(
        Rectangle((0.2, 0.7 + i * 0.08), 2.4, 0.08, color=["#44758c", "#bbd4df"][i % 2])
    )
chip.text(2.8, 1.0, "DBR", fontsize=9)
chip.add_patch(Rectangle((0.2, 1.4), 2.4, 2.0, facecolor="#f9e5c4"))
z = np.linspace(1.4, 3.4, 500)
field_intensity = np.sin(2 * np.pi * (z - 1.4)) ** 2
chip.plot(0.5 + 1.7 * field_intensity, z, color="#b64239", lw=1.5)
for level in [1.65, 2.15, 2.65, 3.15]:
    chip.plot([0.2, 2.6], [level, level], color="#673d80", lw=2)
chip.text(2.8, 2.4, "QWs", fontsize=9)
chip.text(1.4, 3.75, "Wells at intensity antinodes", ha="center", fontsize=9)
fig.tight_layout()

No description has been provided for this image

## 2. Cavity modes, a birefringent plate and an etalon¶

For a nondispersive linear cavity of one-way optical length L, the modes obey nu_q=q*c/(2L), with FSR=c/(2L). Mirror phase and group delay can modify the effective length; we omit them here.

BRF / Lyot: resolve a linearly polarized field along two crystal axes, accumulate a relative retardance, then project back onto the selected polarization. An ideal plate at 45 degrees between parallel polarizers has T=cos²(delta/2), delta=2pinuDelta_nd/c. In a real Brewster-cut intracavity plate the geometry and round trip require a Jones-matrix model. Here we shift the ideal passband to zero detuning and hold Delta_n fixed.

Etalon: sum multiply reflected fields in a plane-parallel slab. For identical lossless faces of power reflectivity R, its Airy transmission is T=1/[1+Fsin²(pidetuning/FSR)], F=4R/(1-R)². The normal-incidence FSR uses the group index: c/(2n_gd). Tilt and temperature move its peaks.

Below, a Gaussian gain envelope times these single-pass ideal filter transmissions is only a relative spectral weight, not a laser threshold or modal-power calculation. Neither a broad passband nor a cavity FSR is the laser linewidth. Several cavity modes may fit inside an etalon peak. The BRF + etalon + PZT hierarchy is used in Burd et al. (2023), Sec. 2 (https://tf.nist.gov/general/pdf/3090.pdf).

In [6]:

def etalon_transmission(detuning_Hz: float | np.ndarray) -> float | np.ndarray:
    """Return dimensionless ideal intensity transmission at detuning in Hz."""
    reflectivity = o["etalon_reflectivity"]
    coefficient = 4 * reflectivity / (1 - reflectivity) ** 2
    phase = np.pi * (np.asarray(detuning_Hz) - o["etalon_detuning_Hz"]) / fsr_etalon
    return 1 / (1 + coefficient * np.sin(phase) ** 2)

def brf_transmission(detuning_Hz: float | np.ndarray) -> float | np.ndarray:
    """Return dimensionless ideal one-plate transmission at detuning in Hz."""
    return np.cos(np.pi * np.asarray(detuning_Hz) / fsr_brf) ** 2

fig, axes = plt.subplots(1, 3, figsize=(13, 3.8))
broad = np.linspace(-6e12, 6e12, 2000)
axes[0].plot(
    broad / 1e12, np.exp(-0.5 * (broad / 3e12) ** 2), label="gain envelope (chosen)"
)
axes[0].plot(broad / 1e12, brf_transmission(broad), label="ideal BRF")
axes[0].set(
    xlabel="Frequency detuning (THz)",
    ylabel="Relative weight",
    title="Coarse selection",
)
medium = np.linspace(-150e9, 150e9, 12000)
axes[1].plot(medium / 1e9, etalon_transmission(medium), color="#6c8d56")
axes[1].set(
    xlabel="Frequency detuning (GHz)",
    ylabel="Etalon transmission",
    title="Repeated etalon orders",
)
modes = np.arange(-8, 9) * fsr_cavity
weights = etalon_transmission(modes) * brf_transmission(modes)
axes[2].vlines(modes / 1e9, 0, weights, color="#245b78")
axes[2].scatter(modes / 1e9, weights, s=12, color="#245b78")
axes[2].set(
    xlabel="Frequency detuning (GHz)",
    ylabel="Relative filter weight",
    title="Allowed cavity modes",
)
axes[0].legend(fontsize=8)
for ax in axes:
    ax.grid(alpha=0.2)
    ax.set_ylim(0, 1.08)
fig.tight_layout()

No description has been provided for this image

## 3. From a disturbed component to frequency noise¶

Differentiating the resonance condition at fixed mode number gives delta_nu/nu = -delta_Lopt/Lopt. This is a useful direct path-length sensitivity, not a complete model of gain pulling, filter dispersion, carrier-index dynamics or mode hops. A gain-peak temperature coefficient is therefore not automatically the laser-frequency temperature coefficient.

Disturbance | Coupling | Measurement / variation
Vibration | mirror or air path | accelerometer coherence; mount change
Temperature | expansion, index, gain pulling | temperature modulation
Pump power | heating and carrier index | RIN and complex Hz/W response
PZT voltage | displacement and resonances | voltage PSD; Hz/V calibration
Reference / sensor | laser-frequency feedback | reference PSD; loop response

Pump stabilization reduced measured frequency noise in a different VECSEL in Lee, Moriya & Hastie (2023), Fig. 4 (https://strathprints.strath.ac.uk/87108/7/Lee-etal-OE-2023-Monolithic-VECSEL-for-stable-kHz-linewidth.pdf). That supports the mechanism, not the amplitudes chosen in this notebook.

In [7]:

length_sensitivity = -nu0 / o["optical_length_m"]
print(
    "1 pm optical-length change -> "
    f"{length_sensitivity * 1e-12:.3f} Hz frequency change"
)
shift = np.linspace(-100e-12, 100e-12, 200)
fig, ax = plt.subplots(figsize=(7, 3.5))
ax.plot(shift * 1e12, length_sensitivity * shift / 1e3)
ax.set(
    xlabel="Optical-length change (pm)",
    ylabel="Frequency shift (kHz)",
    title="Fixed-mode, nondispersive sensitivity",
)
ax.grid(alpha=0.3)
fig.tight_layout()

1 pm optical-length change -> -2145.205 Hz frequency change

No description has been provided for this image

## 4. A synthetic noise budget and two different locks¶

S_nu(f) is a one-sided frequency-noise PSD in Hz²/Hz; f is an ordinary Fourier frequency in Hz, not an angular frequency. ASD is its square root. For an input x with transfer H_nu,x(f), S_nu=|H|²*S_x. Independent inputs add as PSDs; correlated inputs require cross spectra. Here the thermal and fast pump paths share the same pump fluctuation, so their complex transfer amplitudes are added before taking |H|². The chosen fast path is an effective carrier/index coupling, not a Henry alpha calculation. The white floor is illustrative; it is not a measured Schawlow–Townes limit. Sharp deterministic tones and mode hops are omitted.

An ideal integral laser-frequency lock has G=fb/(if). Its output PSD is |1/(1+G)|²S_free + |G/(1+G)|²*S_reference, assuming independent inputs. The reference term below includes sensor noise expressed as equivalent Hz. Delay, actuator limits and servo resonances are omitted.

A doubling-cavity tracking lock instead moves that cavity to follow the incident laser. It suppresses relative detuning, not the seed laser's absolute frequency noise. Conversion to intensity noise needs the optical discriminator and operating point; at the exact peak the static first derivative of transmitted power with detuning is zero. We do not infer UV RIN from a lock bandwidth alone.

In [8]:

f = np.geomspace(1.0, 1e6, 6000)
length_psd = (n["length_asd_m_per_sqrtHz"] / (1 + (f / 3000) ** 2)) ** 2
length_psd *= 1 + 80 / (1 + ((f - 500) / 20) ** 2)
temperature_psd = n["temperature_asd_K_per_sqrtHz"] ** 2 / (1 + (f / 5) ** 2)
pump_rin_psd = n["pump_rin_asd_per_sqrtHz"] ** 2 * (
    1 + 50 / (1 + ((f - 5000) / 400) ** 2)
)
pump_transfer = (
    n["pump_thermal_Hz_per_W"] / (1 + 1j * f / 300) + n["pump_fast_Hz_per_W"]
)
parts = {
    "mechanical / air path": length_sensitivity**2 * length_psd,
    "temperature": n["thermal_tuning_Hz_per_K"] ** 2 * temperature_psd,
    "pump (shared thermal + fast paths)": np.abs(pump_transfer) ** 2
    * n["pump_power_W"] ** 2
    * pump_rin_psd,
    "PZT driver": (n["pzt_tuning_Hz_per_V"] * n["driver_asd_V_per_sqrtHz"]) ** 2
    / (1 + (f / 1000) ** 2),
    "white frequency noise": np.full_like(f, n["white_frequency_psd_Hz2_per_Hz"]),
}
free_psd = sum(parts.values())
loop = n["servo_bandwidth_Hz"] / (1j * f)
suppression = np.abs(1 / (1 + loop)) ** 2
tracking = np.abs(loop / (1 + loop)) ** 2
reference_psd = 25 + 2500 / (1 + (f / 10) ** 2)
locked_psd = suppression * free_psd + tracking * reference_psd
shg_detuning_psd = suppression * free_psd
fig, axes = plt.subplots(1, 3, figsize=(13, 4))
for label, psd in parts.items():
    axes[0].loglog(f, psd, label=label)
axes[0].loglog(f, free_psd, "k", lw=2, label="total")
axes[0].set_title("Chosen technical-noise examples")
axes[0].legend(fontsize=7.5, loc="lower left")
axes[1].loglog(f, free_psd, label="free seed")
axes[1].loglog(f, locked_psd, label="frequency-locked seed")
axes[1].loglog(f, reference_psd, ":", label="reference + sensor")
axes[1].set_title("Actuate the laser frequency")
axes[1].legend(fontsize=8)
axes[2].loglog(f, free_psd, label="seed stays unchanged")
axes[2].loglog(f, shg_detuning_psd, label="relative SHG detuning")
axes[2].set_title("Actuate a following SHG cavity")
axes[2].legend(fontsize=8)
for ax in axes:
    ax.set(xlabel="Fourier frequency (Hz)", ylabel=r"One-sided PSD (Hz$^2$/Hz)")
    ax.grid(alpha=0.2)
fig.tight_layout()
for label, psd in [("free seed", free_psd), ("frequency-locked seed", locked_psd)]:
    print(
        f"{label}: RMS frequency deviation over 1 Hz–1 MHz = "
        f"{np.sqrt(trapezoid(psd, f)):.3f} Hz (not linewidth)"
    )

free seed: RMS frequency deviation over 1 Hz–1 MHz = 32611.007 Hz (not linewidth)
frequency-locked seed: RMS frequency deviation over 1 Hz–1 MHz = 31668.258 Hz (not linewidth)

No description has been provided for this image

## 5. Why an integrated PSD is not automatically a linewidth¶

For Gaussian stationary frequency noise, phase obeys d_phi/dt=2pidelta_nu. The phase-increment variance is 4integral[S_nu(f)sin²(piftau)/f² df]. Since a Gaussian phase increment has <exp(i*delta_phi)>=exp(-variance/2), the normalized field coherence is

$$g^{(1)}(\tau)=\exp\left[-2\int_0^\infty S_\nu(f) \frac{\sin^2(\pi f\tau)}{f^2}\,df\right].$$

The optical line shape is the Fourier transform of this coherence. For ideal white S_nu=h0 over all positive frequencies, the integral gives g1=exp(-pi²h0|tau|), hence a Lorentzian FWHM=pi*h0. In contrast, sqrt(integral S_nu df) is a bandwidth-dependent RMS frequency deviation. Colored noise, drift and a finite observation interval require the spectrum and measurement procedure to be stated; no universal linewidth multiplier converts that RMS value into FWHM.

This is the frequency-noise/coherence approach discussed by Di Domenico, Schilt & Thomann (2010) (https://doi.org/10.1364/AO.49.004801) and applied to a VECSEL in Lee et al. (2023), Sec. 4 (https://strathprints.strath.ac.uk/87108/7/Lee-etal-OE-2023-Monolithic-VECSEL-for-stable-kHz-linewidth.pdf). Our numerical curves assume the PSD is zero outside 1 Hz–1 MHz. They are band-limited coherence examples, not claimed measured linewidths.

In [9]:

def coherence_from_psd(
    frequency_Hz: np.ndarray, psd_Hz2_per_Hz: np.ndarray, delay_s: np.ndarray
) -> np.ndarray:
    """Return dimensionless Gaussian field coherence for one-sided, band-limited PSD."""
    kernel = np.sin(np.pi * np.outer(delay_s, frequency_Hz)) ** 2 / frequency_Hz**2
    return np.exp(-2 * trapezoid(kernel * psd_Hz2_per_Hz, frequency_Hz, axis=1))

tau = np.linspace(0, 200e-6, 500)
h0 = n["white_frequency_psd_Hz2_per_Hz"]
fig, axes = plt.subplots(1, 2, figsize=(11, 3.8))
axes[0].plot(
    tau * 1e6, coherence_from_psd(f, free_psd, tau), label="free seed (band-limited)"
)
axes[0].plot(
    tau * 1e6,
    coherence_from_psd(f, locked_psd, tau),
    label="frequency-locked (band-limited)",
)
axes[0].plot(
    tau * 1e6, np.exp(-np.pi**2 * h0 * tau), "--", label="ideal white floor only"
)
axes[0].set(
    xlabel="Delay (µs)",
    ylabel="Normalized field coherence",
    title="Coherence depends on the PSD shape",
)
axes[0].legend(fontsize=8)
white_fwhm = np.pi * h0
if white_fwhm > 0:
    detuning = np.linspace(-4 * white_fwhm, 4 * white_fwhm, 1000)
    axes[1].plot(detuning / 1e3, 1 / (1 + (2 * detuning / white_fwhm) ** 2))
    axes[1].axhline(0.5, color="gray", ls=":")
    axes[1].set(
        xlabel="Optical frequency detuning (kHz)",
        ylabel="Normalized spectral power",
        title=f"Ideal white-noise line: FWHM {white_fwhm/1e3:.3f} kHz",
    )
else:
    axes[1].text(0.5, 0.5, "Zero white floor: delta-line limit", ha="center")
for ax in axes:
    ax.grid(alpha=0.2)
fig.tight_layout()
print(
    f"Ideal white-only Lorentzian FWHM = {white_fwhm:.6f} Hz; "
    "not total technical linewidth"
)

Ideal white-only Lorentzian FWHM = 3141.592654 Hz; not total technical linewidth

No description has been provided for this image

## Checks, exercises and a measurement plan¶

The checks below test periodic transmission, the exact resonance shift, the ideal feedback limit, and an independent white-noise coherence limit. They do not validate a particular VECSEL's noise amplitudes.

1. Double the optical length. Predict both the FSR and Hz-per-pm sensitivity.
2. Move the etalon peak by half a cavity FSR. Which modes have similar filter weight? Explain why this alone cannot predict mode competition.
3. Reduce pump ASD tenfold. Its frequency-noise PSD should fall 100-fold; identify where other noise terms now dominate.
4. Increase the ideal servo bandwidth. Identify the reference-noise floor and explain why a real loop also needs phase-margin and actuator checks.
5. Change the integration band and explain why RMS deviation changes even for white noise while its ideal Lorentzian FWHM is unchanged.

To contribute real data, include a calibrated frequency discriminator or beat note, the reference-laser noise, PSD normalization, observation time, frequency band, and any detrending/windowing. Measure transfer functions rather than replacing them by a gain-peak temperature slope. Record RIN and cross spectra where inputs may be correlated. A scanning-cavity width, mode spacing and an optical beat-note linewidth are different observables.

In [10]:

assert np.isclose(etalon_transmission(o["etalon_detuning_Hz"]), 1.0)
assert np.isclose(etalon_transmission(o["etalon_detuning_Hz"] + fsr_etalon), 1.0)
assert np.isclose(brf_transmission(fsr_brf), 1.0)
delta_length = 1e-12
exact_shift = -nu0 * delta_length / (o["optical_length_m"] + delta_length)
assert np.isclose(length_sensitivity * delta_length, exact_shift, rtol=1e-9)
assert np.allclose(suppression + tracking, 1.0)
assert np.isclose(coherence_from_psd(f, free_psd, np.array([0.0]))[0], 1.0)
check_f = np.geomspace(1e-4, 1e9, 100000)
check_tau = np.array([1e-6, 1e-5])
white_check = coherence_from_psd(check_f, np.full_like(check_f, 1000.0), check_tau)
assert np.allclose(white_check, np.exp(-np.pi**2 * 1000.0 * check_tau), rtol=0.002)
print("All teaching-model checks passed.")

All teaching-model checks passed.

## Further reading¶

- Burd et al. 2016: magnesium VECSEL systems (https://arxiv.org/abs/1606.03484).
- Burd et al. 2023: cavity, chip and filtering (https://tf.nist.gov/general/pdf/3090.pdf).
- Lee, Moriya & Hastie 2023: technical noise and linewidth measurements (https://strathprints.strath.ac.uk/87108/7/Lee-etal-OE-2023-Monolithic-VECSEL-for-stable-kHz-linewidth.pdf).
- Di Domenico et al. 2010: frequency noise and line shape (https://doi.org/10.1364/AO.49.004801).
- In-house VECSEL narrative and evidence labels (https://uwarring82.github.io/mg-plus-uv-chain/tutorials/vecsel-systems.html).
- Student contribution guide (https://uwarring82.github.io/mg-plus-uv-chain/tutorials/).

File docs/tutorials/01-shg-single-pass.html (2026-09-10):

--- layout: notebook title: "Tutorial 1 — From Boyd–Kleinman to γ_SHG" description: Tutorial notebook (01-shg-single-pass). Architecture-neutral; uses /src/ primitives only. ---

# Tutorial 1 — From Boyd–Kleinman to γ_SHG¶

Architecture-neutral · pre-G1 admissible

This notebook explains how the dimensionless Boyd–Kleinman (BK) focusing factor $h_m$ is turned into the engineering single-pass efficiency coefficient $\gamma_\mathrm{SHG}$ (units W⁻¹). It is the first stepping stone toward answering:

"Given a crystal, a pump wavelength, and a focused beam — how much harmonic power comes out in a single pass?"

No cavity physics yet; that is Tutorial 2.

## Run in Google Colab¶

Open this notebook in Colab (https://colab.research.google.com/github/uwarring82/mg-plus-uv-chain/blob/main/docs/tutorials/01-shg-single-pass.ipynb). Save a copy to your Drive, then run all cells using a standard CPU runtime. The setup cell below downloads the reviewed code and inputs when no local project checkout is present. No Drive mount is needed. For an experiment, edit parameter_overrides below; your changes then travel with the notebook. Student guide and exercises (https://uwarring82.github.io/mg-plus-uv-chain/tutorials/).

In [1]:

# -----------------------------------------------------------------------------
# Imports and path setup
# -----------------------------------------------------------------------------
from __future__ import annotations

import math
import os
import subprocess
import sys
import tempfile
from pathlib import Path

# A local checkout uses its own code. Colab starts without a checkout, so
# fetch a fixed reviewed revision into a temporary runtime directory.
REFERENCE_REVISION = "3466c3262aa72af93f10a3699c48782d401548f8"
REPO_ROOT = Path.cwd().resolve()
while not (REPO_ROOT / "src" / "enhancement_cavity.py").is_file():
    if REPO_ROOT == REPO_ROOT.parent:
        break
    REPO_ROOT = REPO_ROOT.parent
if not (REPO_ROOT / "src" / "enhancement_cavity.py").is_file():
    REPO_ROOT = Path(tempfile.mkdtemp(prefix="mg-uv-tutorial-"))
    subprocess.run(
        ["git", "clone", "--quiet",
         "https://github.com/uwarring82/mg-plus-uv-chain.git", str(REPO_ROOT)],
        check=True,
    )
    subprocess.run(
        ["git", "-C", str(REPO_ROOT), "checkout", "--quiet", REFERENCE_REVISION],
        check=True,
    )
    subprocess.run(
        [sys.executable, "-m", "pip", "install", "--quiet", "-e", str(REPO_ROOT)],
        check=True,
    )
    os.chdir(REPO_ROOT)
    print("Runtime code and inputs:", REFERENCE_REVISION)
sys.path.insert(0, str(REPO_ROOT))

import matplotlib.pyplot as plt  # noqa: E402
import numpy as np  # noqa: E402
import yaml  # noqa: E402

from src import boyd_kleinman as bk  # noqa: E402
from src.shg_single_pass import (  # noqa: E402
    boyd_kleinman_K_factor,
    gamma_shg_coefficient,
    single_pass_conversion_fraction,
    single_pass_harmonic_power_W,
)

print("Imports OK")

Imports OK

## Your experiment¶

Leave the dictionary empty to reproduce the bundled example. Then try {"crystal": {"d_eff_pm_per_V": 1.68}} and run this cell and all cells below it again. Change this cell rather than runtime files so saving the notebook preserves your experiment. Input names and units are listed in the paired YAML file.

In [2]:

parameter_overrides = {}

## 1. The Boyd–Kleinman focusing factor¶

Boyd & Kleinman (1968) showed that, for a focused Gaussian pump in a non-depleted crystal, the harmonic power is

$$P_{2\omega} = K \; L \; k_1 \; h \; P_\omega^2$$

where $h$ is a dimensionless double integral that depends only on geometric and optical parameters:

Symbol | Meaning
$\xi = L/b$ | focusing parameter ($b = 2z_R$ is the confocal parameter)
$\sigma = \tfrac{1}{2}\Delta k \, b$ | phase mismatch
$\beta = \tfrac{1}{2}\rho\sqrt{L k_1}$ | walk-off parameter
$\alpha_1 L$, $\alpha_2 L$ | separate intensity absorption depths (zero here)
$\mu = 2z_\mathrm{focus}/L-1$ | focus offset from crystal centre

Nonzero legacy kappa is rejected: use alpha_omega_L and alpha_2omega_L separately. This tutorial uses zero absorption. Conventions and normalization follow Daniel et al., Eqs. 1–3 (https://arxiv.org/abs/2009.08430).

In the lab you tune $\sigma$ (temperature or angle) for maximum conversion. The $\sigma$-optimised version is $h_m(\xi, \beta)$ for the centred, lossless case used here.

In [3]:

# Quick look: h_m(ξ) for several walk-off parameters β.
# All curves optimise σ; arctan²(ξ)/ξ would only give the σ=0 limit.
xi_grid = np.linspace(0.2, 6.0, 150)

fig, ax = plt.subplots(figsize=(8, 4.5))

# β = 0  →  σ-optimised; arctan²(ξ)/ξ is only the σ=0 limit.
h_beta0 = np.array([bk.h_m_factor(x) for x in xi_grid])
ax.plot(xi_grid, h_beta0, lw=2, label=r"$\beta = 0$ (σ-optimised)")

# β = 1 and β = 2  →  numerical (a few evaluations, still fast)
for beta_val in [1.0, 2.0]:
    h_vals = []
    for xi in xi_grid[::5]:  # coarse sub-sample for speed
        h_vals.append(bk.h_m_factor(xi=xi, beta=beta_val, kappa=0.0, mu=0.0))
    ax.plot(xi_grid[::5], h_vals, "o-", ms=3, label=rf"$\beta = {beta_val}$")

# Mark the classic BK optimum (β = 0, σ-optimised)
xi_opt, h_max = bk.h_m_optimum(beta=0.0, kappa=0.0, mu=0.0)
ax.axvline(xi_opt, ls="--", color="C2", lw=1, alpha=0.6,
           label=rf"$\xi_\mathrm{{opt}} \approx {xi_opt:.2f}$")
ax.axhline(h_max, ls=":", color="C2", lw=1, alpha=0.6)
ax.plot([xi_opt], [h_max], "C2*", ms=12,
        label=rf"$h_m^\max = {h_max:.3f}$")

ax.set_xlabel(r"$\xi = L / b$")
ax.set_ylabel(r"$h_m(\xi, \beta)$")
ax.set_title(r"BK $\sigma$-optimised focusing factor for several walk-off parameters")
ax.legend(loc="upper right", fontsize=9)
ax.grid(alpha=0.3)
ax.set_ylim(0, 1.2)
fig.tight_layout()

print(f"Classic BK optimum:  ξ_opt = {xi_opt:.3f},  h_m_max = {h_max:.4f}")

Classic BK optimum:  ξ_opt = 2.838,  h_m_max = 1.0677

No description has been provided for this image

Take-away. Walk-off drags the optimum to smaller ξ (looser focus) and suppresses the peak $h_m$. For a walk-off-limited crystal you do not simply use the textbook ξ ≈ 2.84 — you must re-optimise.

## 2. From $h_m$ to the engineering coefficient $\gamma_\mathrm{SHG}$¶

The material constant $K$ packages all the wavelength- and crystal-specific physics:

$$K = \frac{2\,\omega^2 \, d_\mathrm{eff}^2}{\pi \, \varepsilon_0 \, c^3 \, n_\omega^2 \, n_{2\omega}}$$

and the single-pass coefficient is

$$\gamma_\mathrm{SHG} = K \; k_1 \; L \; h_m$$

so that

$$P_{2\omega} = \gamma_\mathrm{SHG} \; P_\omega^2 \qquad (\text{small-signal})$$

$$P_{2\omega} = P_\omega \; \tanh^2\!\bigl(\sqrt{\gamma_\mathrm{SHG} \, P_\omega}\bigr) \qquad (\text{depleted})$$

In [4]:

# -----------------------------------------------------------------------------
# Load generic parameters from the paired YAML
# -----------------------------------------------------------------------------
YAML_PATH = REPO_ROOT / "notebooks" / "tutorials" / "01-params.yaml"
with YAML_PATH.open() as f:
    params = yaml.safe_load(f)

# Apply saved notebook experiments to the bundled YAML defaults.
for key, value in parameter_overrides.items():
    if key not in params:
        raise KeyError(f"Unknown parameter section: {key}")
    if isinstance(value, dict):
        unknown = value.keys() - params[key].keys()
        if unknown:
            raise KeyError(f"Unknown parameters in {key}: {sorted(unknown)}")
        params[key].update(value)
    else:
        params[key] = value

c = params["crystal"]
d_eff = c["d_eff_pm_per_V"] * 1e-12  # convert pm/V → m/V
n_o = c["n_omega"]
n_2 = c["n_2omega"]
lam = c["wavelength_nm"] * 1e-9
L_mm = c["length_mm"]
L = L_mm * 1e-3

foc = params["focusing"]
w0_um = foc["w0_um"]
rho_mrad = foc["walk_off_angle_mrad"]

print("Loaded parameters from 01-params.yaml")
print(f"  d_eff = {d_eff*1e12:.2f} pm/V")
print(f"  n_ω = {n_o},  n_2ω = {n_2}")
print(f"  λ = {lam*1e9:.0f} nm,  L = {L_mm:.0f} mm")
print(f"  w0 = {w0_um} μm,  ρ = {rho_mrad} mrad")

Loaded parameters from 01-params.yaml
  d_eff = 0.84 pm/V
  n_ω = 1.605,  n_2ω = 1.62
  λ = 1118 nm,  L = 18 mm
  w0 = None μm,  ρ = 0.0 mrad

### 2.1 Compute the BK focusing factor¶

If w0_um is null in the YAML, we use the σ-optimised BK waist. Otherwise we compute ξ from the specified waist and evaluate $h_m$ there.

In [5]:

if w0_um is None:
    # Use the BK σ-optimum (β includes walk-off if ρ > 0)
    beta = 0.5 * (rho_mrad * 1e-3) * math.sqrt(L * 2 * math.pi * n_o / lam)
    xi_opt_val, h_m_val = bk.h_m_optimum(beta=beta, kappa=0.0, mu=0.0)
    w0_calc = math.sqrt(L * lam / (2 * math.pi * n_o * xi_opt_val))
    print(f"BK σ-optimum:  ξ = {xi_opt_val:.3f},  h_m = {h_m_val:.4f}")
    print(f"Corresponding waist: w0 = {w0_calc*1e6:.2f} μm")
else:
    w0_m = w0_um * 1e-6
    xi_val = L * lam / (2 * math.pi * n_o * w0_m**2)
    beta = 0.5 * (rho_mrad * 1e-3) * math.sqrt(L * 2 * math.pi * n_o / lam)
    h_m_val = bk.h_m_factor(xi=xi_val, beta=beta, kappa=0.0, mu=0.0)
    print(f"Specified waist:  ξ = {xi_val:.3f},  h_m = {h_m_val:.4f}")

BK σ-optimum:  ξ = 2.838,  h_m = 1.0677
Corresponding waist: w0 = 26.52 μm

### 2.2 Compute γ_SHG and the single-pass harmonic power¶

In [6]:

K = boyd_kleinman_K_factor(d_eff, n_o, n_2, lam)
gamma = gamma_shg_coefficient(d_eff, n_o, n_2, lam, L, h_m_val)

print(f"Material constant K = {K:.4e} W⁻¹")
print(f"Single-pass coefficient γ_SHG = {gamma:.4e} W⁻¹")

# Plot single-pass conversion vs pump power
P_range = np.linspace(0.01, 50.0, 200)
h_small = gamma * P_range**2
h_depl = np.array([
    single_pass_harmonic_power_W(p, gamma, "depleted") for p in P_range
])

fig, ax = plt.subplots(figsize=(8, 4))
ax.plot(P_range, h_small, "--", lw=1.5, alpha=0.7, label=r"Small-signal  $\gamma P^2$")
ax.plot(P_range, h_depl, "-", lw=2, label=r"Depleted  $P \tanh^2(\sqrt{\gamma P})$")

# Mark a small-signal reference value; auto now uses tanh² everywhere.
P_reference = 0.05 / gamma
ax.axvline(P_reference, ls=":", color="C2", lw=1, alpha=0.6,
           label=f"γP = 0.05  ({P_reference:.1f} W)")

ax.set_xlabel(r"Pump power $P_\omega$ (W)")
ax.set_ylabel(r"Harmonic power $P_{2\omega}$ (W)")
ax.set_title("Single-pass harmonic generation")
ax.legend(loc="upper left")
ax.grid(alpha=0.3)
ax.set_xlim(0, 50)
ax.set_ylim(0, min(50, max(h_depl) * 1.2))
fig.tight_layout()

Material constant K = 1.2808e-09 W⁻¹
Single-pass coefficient γ_SHG = 2.2204e-04 W⁻¹

No description has been provided for this image

Take-away. At low power the two curves sit on top of each other. The default auto uses the depleted model continuously; the explicit small-signal approximation increasingly overestimates conversion: the pump is being consumed, and the conversion fraction can never exceed 100 % (the Manley–Rowe ceiling).

## 3. Conversion fraction vs pump power¶

The conversion fraction $\eta = P_{2\omega} / P_\omega$ is what the cavity solver (Tutorial 3) consumes. It is not simply $\gamma P_\omega$ outside the small-signal regime.

In [7]:

eta_small = gamma * P_range
eta_depl = np.array([
    single_pass_conversion_fraction(p, gamma, "depleted") for p in P_range
])

fig, ax = plt.subplots(figsize=(8, 4))
ax.plot(P_range, eta_small * 100, "--", lw=1.5, alpha=0.7,
        label=r"Small-signal  $\gamma P$")
ax.plot(P_range, eta_depl * 100, "-", lw=2,
        label=r"Depleted  $\tanh^2(\sqrt{\gamma P})$")
ax.axhline(100, ls=":", color="gray", lw=1, alpha=0.5)
ax.set_xlabel(r"Pump power $P_\omega$ (W)")
ax.set_ylabel(r"Conversion fraction  $\eta$ (%)")
ax.set_title("Single-pass conversion fraction")
ax.legend(loc="lower right")
ax.grid(alpha=0.3)
ax.set_xlim(0, 50)
ax.set_ylim(0, 105)
fig.tight_layout()

No description has been provided for this image

## 4. Try this¶

Open 01-params.yaml next to this notebook and change the crystal parameters. For example:

- Set d_eff_pm_per_V: 2.2 (a high-nonlinearity crystal like KNB)
- Set length_mm: 25
- Set walk_off_angle_mrad: 50 (a walk-off-limited geometry)

Re-run the cells above and watch how $\gamma_\mathrm{SHG}$ and the conversion curves shift.

In [8]:

print("Tutorial 01 complete.")

Tutorial 01 complete.

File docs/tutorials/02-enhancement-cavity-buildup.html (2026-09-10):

--- layout: notebook title: "Tutorial 2 — Passive Enhancement-Cavity Buildup" description: Tutorial notebook (02-enhancement-cavity-buildup). Architecture-neutral; uses /src/ primitives only. ---

# Tutorial 2 — Passive Enhancement-Cavity Buildup¶

Architecture-neutral · pre-G1 admissible

Before adding a nonlinear crystal, it helps to understand how a passive ring cavity builds up circulating power. This notebook derives the Airy formula in plain language and shows where the impedance-matched maximum sits.

"Given an input coupler with transmission $T$ and a round-trip passive loss $L$, what is the circulating power?"

## Run in Google Colab¶

Open this notebook in Colab (https://colab.research.google.com/github/uwarring82/mg-plus-uv-chain/blob/main/docs/tutorials/02-enhancement-cavity-buildup.ipynb). Save a copy to your Drive, then run all cells using a standard CPU runtime. The setup cell below downloads the reviewed code and inputs when no local project checkout is present. No Drive mount is needed. For an experiment, edit parameter_overrides below; your changes then travel with the notebook. Student guide and exercises (https://uwarring82.github.io/mg-plus-uv-chain/tutorials/).

In [1]:

# -----------------------------------------------------------------------------
# Imports and path setup
# -----------------------------------------------------------------------------
from __future__ import annotations

import math
import os
import subprocess
import sys
import tempfile
from pathlib import Path

# A local checkout uses its own code. Colab starts without a checkout, so
# fetch a fixed reviewed revision into a temporary runtime directory.
REFERENCE_REVISION = "3466c3262aa72af93f10a3699c48782d401548f8"
REPO_ROOT = Path.cwd().resolve()
while not (REPO_ROOT / "src" / "enhancement_cavity.py").is_file():
    if REPO_ROOT == REPO_ROOT.parent:
        break
    REPO_ROOT = REPO_ROOT.parent
if not (REPO_ROOT / "src" / "enhancement_cavity.py").is_file():
    REPO_ROOT = Path(tempfile.mkdtemp(prefix="mg-uv-tutorial-"))
    subprocess.run(
        ["git", "clone", "--quiet",
         "https://github.com/uwarring82/mg-plus-uv-chain.git", str(REPO_ROOT)],
        check=True,
    )
    subprocess.run(
        ["git", "-C", str(REPO_ROOT), "checkout", "--quiet", REFERENCE_REVISION],
        check=True,
    )
    subprocess.run(
        [sys.executable, "-m", "pip", "install", "--quiet", "-e", str(REPO_ROOT)],
        check=True,
    )
    os.chdir(REPO_ROOT)
    print("Runtime code and inputs:", REFERENCE_REVISION)
sys.path.insert(0, str(REPO_ROOT))

import matplotlib.pyplot as plt  # noqa: E402
import numpy as np  # noqa: E402
import yaml  # noqa: E402

from src.enhancement_cavity import circulating_power, passive_buildup  # noqa: E402

print("Imports OK")

Imports OK

## Your experiment¶

Leave the dictionary empty to reproduce the bundled example. Then try {"cavity": {"loss_per_pass": 0.01}} and run this cell and all cells below it again. Change this cell rather than runtime files so saving the notebook preserves your experiment. Input names and units are listed in the paired YAML file.

In [2]:

parameter_overrides = {}

## 1. The Airy buildup formula¶

For a ring cavity on resonance, the circulating power is

$$\frac{P_\mathrm{circ}}{P_\mathrm{in}} = \frac{T}{(1 - \sqrt{R\,(1-L)})^2}$$

where $R = 1-T$ is the input-coupler reflectivity and $L$ is the round-trip passive loss excluding the input coupler.

Why this formula? On each round trip the beam:

1. Reflects off the input coupler → factor $R$
2. Suffers passive loss → factor $1-L$
3. Returns to the input coupler

The amplitude that survives one round trip is $\sqrt{R(1-L)}$. The geometric series of all round trips gives the denominator $(1 - \sqrt{R(1-L)})^2$.

In [3]:

# -----------------------------------------------------------------------------
# Load parameters
# -----------------------------------------------------------------------------
YAML_PATH = REPO_ROOT / "notebooks" / "tutorials" / "02-params.yaml"
with YAML_PATH.open() as f:
    params = yaml.safe_load(f)

# Apply saved notebook experiments to the bundled YAML defaults.
for key, value in parameter_overrides.items():
    if key not in params:
        raise KeyError(f"Unknown parameter section: {key}")
    if isinstance(value, dict):
        unknown = value.keys() - params[key].keys()
        if unknown:
            raise KeyError(f"Unknown parameters in {key}: {sorted(unknown)}")
        params[key].update(value)
    else:
        params[key] = value

c = params["cavity"]
P_in = c["power_in_W"]
L_loss = c["loss_per_pass"]
gamma = c["gamma_shg"]

sweep = params["sweep"]
T_min = sweep["T_IC_min"]
T_max = sweep["T_IC_max"]
n_pts = sweep["n_points"]

print(f"Parameters: P_in = {P_in} W,  L = {L_loss},  γ = {gamma} W⁻¹")

Parameters: P_in = 1.0 W,  L = 0.02,  γ = 0.0 W⁻¹

## 2. Buildup curves for several passive losses¶

In [4]:

T_grid = np.linspace(T_min, T_max, n_pts)
losses = [0.005, 0.01, 0.02, 0.05]

fig, ax = plt.subplots(figsize=(8, 4.5))
for L_val in losses:
    buildup = [passive_buildup(T, L_val) for T in T_grid]
    ax.plot(T_grid * 100, buildup, lw=2, label=f"L = {L_val:.3f}")
    # Mark the impedance-matched maximum at T = L
    idx = np.argmin(np.abs(T_grid - L_val))
    ax.plot([L_val * 100], [buildup[idx]], "o", ms=6)

ax.set_xlabel("Input-coupler transmission  T (%)")
ax.set_ylabel(r"Buildup  $P_\mathrm{circ} / P_\mathrm{in}$")
ax.set_title("Passive ring-cavity buildup vs. input-coupler transmission")
ax.legend(loc="upper right", title="Passive loss")
ax.grid(alpha=0.3)
ax.set_yscale("log")
fig.tight_layout()

No description has been provided for this image

Take-away. Each curve has a sharp maximum at T = L (the open circles). This is the impedance-matched point: the input coupler transmits exactly as much power as the cavity loses per round trip, so no power is reflected back to the source. At this point the buildup is $1/L$ — for $L = 0.01$ the circulating power is 100× the input power.

## 3. Circulating power with nonlinear loss¶

When a crystal is inside the cavity, each round trip converts a fraction $\eta_\mathrm{nl}$ of the circulating power to harmonic. The nonlinear loss modifies the buildup. Here we compare the passive curve with the nonlinear curve for a small SHG coefficient.

In [5]:

T_grid = np.linspace(0.001, 0.10, 200)
L_val = 0.02
gamma_small = 1e-3  # W⁻¹ — small enough to stay in the small-signal regime

buildup_passive = [passive_buildup(T, L_val) for T in T_grid]
buildup_nonlinear = [
    circulating_power(P_in, T, L_val, gamma_small) / P_in for T in T_grid
]

fig, ax = plt.subplots(figsize=(8, 4.5))
ax.plot(T_grid * 100, buildup_passive, "-", lw=2, label="Passive (γ = 0)")
ax.plot(T_grid * 100, buildup_nonlinear, "--", lw=2,
        label=rf"Nonlinear ($\gamma = {gamma_small}$ W⁻¹)")
ax.axvline(L_val * 100, ls=":", color="gray", lw=1, alpha=0.6,
           label=f"Impedance match  T = L = {L_val:.3f}")
ax.set_xlabel("Input-coupler transmission  T (%)")
ax.set_ylabel(r"Buildup  $P_\mathrm{circ} / P_\mathrm{in}$")
ax.set_title("Passive vs. small-nonlinear-loss buildup")
ax.legend(loc="upper right")
ax.grid(alpha=0.3)
ax.set_yscale("log")
fig.tight_layout()

No description has been provided for this image

Take-away. Even a tiny SHG coefficient pulls the optimum to slightly larger T (the nonlinear loss acts like extra round-trip loss). The shift is small here, but it grows with pump power — that is the subject of Tutorial 3.

## 4. Try this¶

Use parameter_overrides to change cavity.loss_per_pass. Try values from 0.001 (very low-loss super-mirror cavity) to 0.10 (a lossy prototype). Re-run the cells and watch how the impedance-matched buildup $1/L$ changes.

In [6]:

print("Tutorial 02 complete.")

Tutorial 02 complete.

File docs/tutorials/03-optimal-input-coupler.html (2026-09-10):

--- layout: notebook title: "Tutorial 3 — Optimal Input-Coupler Reflectivity" description: Tutorial notebook (03-optimal-input-coupler). Architecture-neutral; uses /src/ primitives only. ---

# Tutorial 3 — Optimal Input-Coupler Reflectivity¶

Architecture-neutral · pre-G1 admissible

This is the notebook that answers the project's motivating question:

"Given a pump power, a passive loss budget, and a single-pass SHG efficiency coefficient — what input-coupler reflectivity should I order from the coating vendor, and how much harmonic power will that produce?"

We give both the closed-form textbook answer (small-signal, Polzik–Kimble) and the numerical solver for the saturated regime.

## Run in Google Colab¶

Open this notebook in Colab (https://colab.research.google.com/github/uwarring82/mg-plus-uv-chain/blob/main/docs/tutorials/03-optimal-input-coupler.ipynb). Save a copy to your Drive, then run all cells using a standard CPU runtime. The setup cell below downloads the reviewed code and inputs when no local project checkout is present. No Drive mount is needed. For an experiment, edit parameter_overrides below; your changes then travel with the notebook. Student guide and exercises (https://uwarring82.github.io/mg-plus-uv-chain/tutorials/).

In [1]:

# -----------------------------------------------------------------------------
# Imports and path setup
# -----------------------------------------------------------------------------
from __future__ import annotations

import math
import os
import subprocess
import sys
import tempfile
from pathlib import Path

# A local checkout uses its own code. Colab starts without a checkout, so
# fetch a fixed reviewed revision into a temporary runtime directory.
REFERENCE_REVISION = "3466c3262aa72af93f10a3699c48782d401548f8"
REPO_ROOT = Path.cwd().resolve()
while not (REPO_ROOT / "src" / "enhancement_cavity.py").is_file():
    if REPO_ROOT == REPO_ROOT.parent:
        break
    REPO_ROOT = REPO_ROOT.parent
if not (REPO_ROOT / "src" / "enhancement_cavity.py").is_file():
    REPO_ROOT = Path(tempfile.mkdtemp(prefix="mg-uv-tutorial-"))
    subprocess.run(
        ["git", "clone", "--quiet",
         "https://github.com/uwarring82/mg-plus-uv-chain.git", str(REPO_ROOT)],
        check=True,
    )
    subprocess.run(
        ["git", "-C", str(REPO_ROOT), "checkout", "--quiet", REFERENCE_REVISION],
        check=True,
    )
    subprocess.run(
        [sys.executable, "-m", "pip", "install", "--quiet", "-e", str(REPO_ROOT)],
        check=True,
    )
    os.chdir(REPO_ROOT)
    print("Runtime code and inputs:", REFERENCE_REVISION)
sys.path.insert(0, str(REPO_ROOT))

import matplotlib.pyplot as plt  # noqa: E402
import numpy as np  # noqa: E402
import yaml  # noqa: E402

from src.enhancement_cavity import (  # noqa: E402
    circulating_power,
    harmonic_output_W,
    optimal_input_coupler,
)

print("Imports OK")

Imports OK

## Your experiment¶

Leave the dictionary empty to reproduce the bundled example. Then try {"cavity": {"power_in_W": 2.0}} and run this cell and all cells below it again. Change this cell rather than runtime files so saving the notebook preserves your experiment. Input names and units are listed in the paired YAML file.

In [2]:

parameter_overrides = {}

## 1. The small-signal closed form¶

In the small-signal limit ($\eta_\mathrm{nl} = \gamma P_\mathrm{circ} \ll 1$) the impedance-match condition is

$$T_\mathrm{match} = L + (1-L)\,\gamma\,P_\mathrm{circ}$$

and because $P_\mathrm{circ} \approx P_\mathrm{in} / T$ at match, this becomes the quadratic

$$T^2 - L\,T - (1-L)\,\gamma\,P_\mathrm{in} = 0$$

whose physical root is

$$T_\mathrm{opt} = \tfrac{1}{2}\Bigl[\,L + \sqrt{L^2 + 4(1-L)\,\gamma\,P_\mathrm{in}}\,\Bigr]$$

This is the Polzik–Kimble result (Opt. Lett. 16, 1400, 1991).

In [3]:

# -----------------------------------------------------------------------------
# Load parameters
# -----------------------------------------------------------------------------
YAML_PATH = REPO_ROOT / "notebooks" / "tutorials" / "03-params.yaml"
with YAML_PATH.open() as f:
    params = yaml.safe_load(f)

# Apply saved notebook experiments to the bundled YAML defaults.
for key, value in parameter_overrides.items():
    if key not in params:
        raise KeyError(f"Unknown parameter section: {key}")
    if isinstance(value, dict):
        unknown = value.keys() - params[key].keys()
        if unknown:
            raise KeyError(f"Unknown parameters in {key}: {sorted(unknown)}")
        params[key].update(value)
    else:
        params[key] = value

c = params["cavity"]
P_in = c["power_in_W"]
L_loss = c["loss_per_pass"]
gamma = c["gamma_shg"]

sens = params["sensitivity"]
gamma_rel = sens["gamma_relative_variation"]
loss_abs = sens["loss_absolute_variation"]

sweep = params["sweep"]
T_min = sweep["T_IC_min"]
T_max = sweep["T_IC_max"]
n_pts = sweep["n_points"]

print(f"Parameters: P_in = {P_in} W,  L = {L_loss},  γ = {gamma} W⁻¹")

Parameters: P_in = 1.0 W,  L = 0.02,  γ = 0.01 W⁻¹

### 1.1 Compute the analytic optimum and compare with the numerical solver¶

In [4]:

# Analytic closed form (small-signal)
T_opt_analytic = (
    L_loss + math.sqrt(L_loss**2 + 4.0 * (1.0 - L_loss) * gamma * P_in)
) / 2.0

# Numerical solver (exact, depleted regime)
T_opt_numerical = optimal_input_coupler(P_in, L_loss, gamma)

P_h_analytic = harmonic_output_W(P_in, T_opt_analytic, L_loss, gamma)
P_h_numerical = harmonic_output_W(P_in, T_opt_numerical, L_loss, gamma)

print(f"Analytic  T_opt = {T_opt_analytic:.5f}  →  P_h = {P_h_analytic:.4f} W")
print(f"Numerical T_opt = {T_opt_numerical:.5f}  →  P_h = {P_h_numerical:.4f} W")
print(f"Deviation in T_opt: {(T_opt_numerical - T_opt_analytic) / T_opt_analytic * 100:+.2f} %")

Analytic  T_opt = 0.10950  →  P_h = 0.8286 W
Numerical T_opt = 0.10653  →  P_h = 0.8288 W
Deviation in T_opt: -2.71 %

Take-away. Compare the approximation with the numerical result at your chosen inputs. Its small-signal assumption requires $\gamma P_\mathrm{circ} \ll 1$; there is no universal accuracy guarantee for a procurement estimate. Input uncertainties remain separate from approximation error.

## 2. Harmonic output vs. input-coupler transmission¶

A 2-D sweep shows the landscape: there is a single maximum, and missing it by even a few percent of T can cost tens of percent in harmonic power.

In [5]:

T_grid = np.linspace(T_min, T_max, n_pts)
P_h_grid = np.array([
    harmonic_output_W(P_in, T, L_loss, gamma) for T in T_grid
])

fig, ax = plt.subplots(figsize=(8, 4.5))
ax.plot(T_grid * 100, P_h_grid, lw=2, label="Exact solver")
ax.axvline(T_opt_numerical * 100, ls="--", color="C2", lw=1.5,
           label=rf"Optimum  $T = {T_opt_numerical*100:.2f}$ %")
ax.axvline(T_opt_analytic * 100, ls=":", color="C3", lw=1.5,
           label=rf"Analytic  $T = {T_opt_analytic*100:.2f}$ %")
ax.plot([T_opt_numerical * 100], [P_h_numerical], "C2*", ms=12)

ax.set_xlabel("Input-coupler transmission  T (%)")
ax.set_ylabel(r"Harmonic output $P_{2\omega}$ (W)")
ax.set_title("Harmonic output vs. input-coupler transmission")
ax.legend(loc="lower left")
ax.grid(alpha=0.3)
fig.tight_layout()

No description has been provided for this image

Take-away. The curve is asymmetric: over-coupling (T too large) is generally less painful than under-coupling (T too small), but the penalty is significant on both sides. When you order coatings, specify the target T at the centre of your expected loss budget and include a tolerance band.

## 3. Sensitivity — how wrong can γ and L be?¶

In practice you never know $\gamma$ or $L$ exactly. Here we sweep both around the nominal values and plot the optimum T and the resulting harmonic output.

In [6]:

# γ sensitivity
gammas = gamma * np.array([1 - gamma_rel, 1.0, 1 + gamma_rel])
fig, axs = plt.subplots(1, 2, figsize=(12, 4.5))

for g in gammas:
    P_h = np.array([harmonic_output_W(P_in, T, L_loss, g) for T in T_grid])
    T_opt = optimal_input_coupler(P_in, L_loss, g)
    axs[0].plot(T_grid * 100, P_h, lw=2, label=rf"$\gamma = {g:.4f}$ W⁻¹")
    axs[0].axvline(T_opt * 100, ls="--", lw=1, alpha=0.5)

axs[0].set_xlabel("Input-coupler transmission  T (%)")
axs[0].set_ylabel(r"Harmonic output $P_{2\omega}$ (W)")
axs[0].set_title(rf"Sensitivity to $\gamma$  (nominal ±{gamma_rel*100:.0f} %)")
axs[0].legend(loc="lower left", fontsize=9)
axs[0].grid(alpha=0.3)

# L sensitivity
Ls = [L_loss - loss_abs, L_loss, L_loss + loss_abs]
for L_val in Ls:
    P_h = np.array([harmonic_output_W(P_in, T, L_val, gamma) for T in T_grid])
    T_opt = optimal_input_coupler(P_in, L_val, gamma)
    axs[1].plot(T_grid * 100, P_h, lw=2, label=rf"$L = {L_val:.4f}$")
    axs[1].axvline(T_opt * 100, ls="--", lw=1, alpha=0.5)

axs[1].set_xlabel("Input-coupler transmission  T (%)")
axs[1].set_ylabel(r"Harmonic output $P_{2\omega}$ (W)")
axs[1].set_title(rf"Sensitivity to $L$  (nominal ±{loss_abs*100:.1f} pp)")
axs[1].legend(loc="lower left", fontsize=9)
axs[1].grid(alpha=0.3)

fig.tight_layout()

# Print numeric summary
print("\nSensitivity summary:")
for g in gammas:
    T_opt = optimal_input_coupler(P_in, L_loss, g)
    P_h = harmonic_output_W(P_in, T_opt, L_loss, g)
    print(f"  γ = {g:.4f} W⁻¹  →  T_opt = {T_opt*100:.2f} %  →  P_h = {P_h:.3f} W")
for L_val in Ls:
    T_opt = optimal_input_coupler(P_in, L_val, gamma)
    P_h = harmonic_output_W(P_in, T_opt, L_val, gamma)
    print(f"  L = {L_val:.4f}    →  T_opt = {T_opt*100:.2f} %  →  P_h = {P_h:.3f} W")

Sensitivity summary:
  γ = 0.0080 W⁻¹  →  T_opt = 9.68 %  →  P_h = 0.809 W
  γ = 0.0100 W⁻¹  →  T_opt = 10.65 %  →  P_h = 0.829 W
  γ = 0.0120 W⁻¹  →  T_opt = 11.53 %  →  P_h = 0.843 W
  L = 0.0150    →  T_opt = 10.40 %  →  P_h = 0.869 W
  L = 0.0200    →  T_opt = 10.65 %  →  P_h = 0.829 W
  L = 0.0250    →  T_opt = 10.91 %  →  P_h = 0.791 W

No description has been provided for this image

Take-away. Read the changes in optimum T and harmonic power from the sweeps at your selected inputs. These independent variations are sensitivity examples, not confidence intervals. If L was fitted using γ, vary and refit them together before interpreting a coating tolerance.

## 4. Procurement implication¶

Suppose you are about to order input-coupler coatings for a new cavity. You have:

- A measured passive loss $L = 0.020 \pm 0.003$
- An estimated γ = 0.010 ± 20 % W⁻¹
- A design pump power $P_\mathrm{in} = 1.0$ W

The table above tells you the optimum T sits in the range 2.5–3.5 %. Ordering a coating at a single fixed T = 2.5 % leaves you under-coupled if the true loss is higher; ordering at T = 4 % leaves you over-coupled if γ is lower than expected.

A robust procurement strategy:

1. Bracket the coating run. Order a small batch at T = 2.5 %, 3.0 %, and 3.5 %. Characterise each in the actual cavity and pick the best.
2. Tunable IC. Use a piezo-actuated wedge or a rotatable Brewster plate to fine-tune the effective T after installation.

## 5. Try this¶

Open 03-params.yaml and change the operating point:

- Double the pump power (power_in_W: 2.0)
- Halve the nonlinearity (gamma_shg: 0.005)
- Make the cavity very lossy (loss_per_pass: 0.08)

Re-run the cells and watch how the optimum T and the sensitivity landscape change.

In [7]:

print("Tutorial 03 complete.")

Tutorial 03 complete.

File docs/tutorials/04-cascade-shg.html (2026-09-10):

--- layout: notebook title: "Tutorial 4 — Two-Stage SHG Cascade" description: Tutorial notebook (04-cascade-shg). Architecture-neutral; uses /src/ primitives only. ---

# Tutorial 4 — Two-Stage SHG Cascade¶

Architecture-neutral · pre-G1 admissible

Many UV sources (including the Friedenauer 2006 baseline) use two enhancement-cavity doubling stages in series: e.g. 1118 nm → 559 nm → 280 nm. This notebook shows how to compose the single-stage physics from Tutorials 1–3 into a cascade, and explains a useful mathematical fact: the cascade optimum factorises exactly.

## Run in Google Colab¶

Open this notebook in Colab (https://colab.research.google.com/github/uwarring82/mg-plus-uv-chain/blob/main/docs/tutorials/04-cascade-shg.ipynb). Save a copy to your Drive, then run all cells using a standard CPU runtime. The setup cell below downloads the reviewed code and inputs when no local project checkout is present. No Drive mount is needed. For an experiment, edit parameter_overrides below; your changes then travel with the notebook. Student guide and exercises (https://uwarring82.github.io/mg-plus-uv-chain/tutorials/).

In [1]:

# -----------------------------------------------------------------------------
# Imports and path setup
# -----------------------------------------------------------------------------
from __future__ import annotations

import math
import os
import subprocess
import sys
import tempfile
from pathlib import Path

# A local checkout uses its own code. Colab starts without a checkout, so
# fetch a fixed reviewed revision into a temporary runtime directory.
REFERENCE_REVISION = "3466c3262aa72af93f10a3699c48782d401548f8"
REPO_ROOT = Path.cwd().resolve()
while not (REPO_ROOT / "src" / "enhancement_cavity.py").is_file():
    if REPO_ROOT == REPO_ROOT.parent:
        break
    REPO_ROOT = REPO_ROOT.parent
if not (REPO_ROOT / "src" / "enhancement_cavity.py").is_file():
    REPO_ROOT = Path(tempfile.mkdtemp(prefix="mg-uv-tutorial-"))
    subprocess.run(
        ["git", "clone", "--quiet",
         "https://github.com/uwarring82/mg-plus-uv-chain.git", str(REPO_ROOT)],
        check=True,
    )
    subprocess.run(
        ["git", "-C", str(REPO_ROOT), "checkout", "--quiet", REFERENCE_REVISION],
        check=True,
    )
    subprocess.run(
        [sys.executable, "-m", "pip", "install", "--quiet", "-e", str(REPO_ROOT)],
        check=True,
    )
    os.chdir(REPO_ROOT)
    print("Runtime code and inputs:", REFERENCE_REVISION)
sys.path.insert(0, str(REPO_ROOT))

import matplotlib.pyplot as plt  # noqa: E402
import numpy as np  # noqa: E402
import yaml  # noqa: E402

from src.enhancement_cavity import harmonic_output_W, optimal_input_coupler  # noqa: E402
from src.shg_cascade import Stage, cascade_output, optimise_cascade  # noqa: E402

print("Imports OK")

Imports OK

## Your experiment¶

Leave the dictionary empty to reproduce the bundled example. Then try {"transport": {"efficiency": 0.50}} and run this cell and all cells below it again. Change this cell rather than runtime files so saving the notebook preserves your experiment. Input names and units are listed in the paired YAML file.

In [2]:

parameter_overrides = {}

## 1. A two-stage example¶

Consider a cascade with:

- Stage 1 (low nonlinearity): γ₁ = 0.001 W⁻¹, L₁ = 0.02
- Stage 2 (high nonlinearity): γ₂ = 0.010 W⁻¹, L₂ = 0.02
- Transport efficiency between stages: ηₜ = 0.95

The pump power into stage 1 is $P_\mathrm{in} = 1.0$ W.

In [3]:

# -----------------------------------------------------------------------------
# Load parameters
# -----------------------------------------------------------------------------
YAML_PATH = REPO_ROOT / "notebooks" / "tutorials" / "04-params.yaml"
with YAML_PATH.open() as f:
    params = yaml.safe_load(f)

# Apply saved notebook experiments to the bundled YAML defaults.
for key, value in parameter_overrides.items():
    if key not in params:
        raise KeyError(f"Unknown parameter section: {key}")
    if isinstance(value, dict):
        unknown = value.keys() - params[key].keys()
        if unknown:
            raise KeyError(f"Unknown parameters in {key}: {sorted(unknown)}")
        params[key].update(value)
    else:
        params[key] = value

s1 = params["stage_1"]
s2 = params["stage_2"]
eta_t = params["transport"]["efficiency"]
P_in = params["power_in_W"]

print(f"Stage 1: L = {s1['loss_per_pass']},  γ = {s1['gamma_shg']} W⁻¹")
print(f"Stage 2: L = {s2['loss_per_pass']},  γ = {s2['gamma_shg']} W⁻¹")
print(f"Transport efficiency: {eta_t}")
print(f"Input power: {P_in} W")

Stage 1: L = 0.02,  γ = 0.001 W⁻¹
Stage 2: L = 0.02,  γ = 0.01 W⁻¹
Transport efficiency: 0.95
Input power: 1.0 W

### 1.1 Optimise each stage independently¶

In [4]:

opt_stages = optimise_cascade(
    P_in,
    stage_params=[(s1["loss_per_pass"], s1["gamma_shg"]),
                  (s2["loss_per_pass"], s2["gamma_shg"])],
    transport_efficiencies=[eta_t],
)

print("Optimised cascade:")
for i, st in enumerate(opt_stages, 1):
    print(f"  Stage {i}:  T_IC = {st.T_IC*100:.3f} %")

Optimised cascade:
  Stage 1:  T_IC = 4.263 %
  Stage 2:  T_IC = 8.025 %

### 1.2 Evaluate the cascade at these operating points¶

In [5]:

result = cascade_output(P_in, opt_stages, [eta_t])

for i, entry in enumerate(result["per_stage"], 1):
    print(f"\nStage {i}:")
    print(f"  Input power      = {entry['input_W']:.4f} W")
    print(f"  Circulating power = {entry['circulating_W']:.2f} W")
    print(f"  Harmonic power   = {entry['harmonic_W']:.4f} W")
    if entry["into_next_stage_W"] is not None:
        print(f"  Into next stage  = {entry['into_next_stage_W']:.4f} W")

print(f"\nTotal harmonic output = {result['total_harmonic_W']:.4f} W")
print(f"Overall efficiency    = {result['total_efficiency']*100:.2f} %")

Stage 1:
  Input power      = 1.0000 W
  Circulating power = 23.46 W
  Harmonic power   = 0.5417 W
  Into next stage  = 0.5146 W

Stage 2:
  Input power      = 0.5146 W
  Circulating power = 6.41 W
  Harmonic power   = 0.3943 W

Total harmonic output = 0.3943 W
Overall efficiency    = 39.43 %

Take-away. Read each stage efficiency from the powers printed above. Their product, including the relay throughput, gives the overall efficiency:

$$\eta_\mathrm{overall} = \eta_1 \times \eta_t \times \eta_2$$

This is power accounting at the evaluated operating points, including depletion; it does not require impedance matching or a small-signal limit.

## 2. Why the cascade factorises exactly¶

You might expect that optimising a cascade requires solving a coupled two-variable problem (T₁ and T₂ jointly). It does not.

The reason is one-way coupling: stage 2 does not feed back into stage 1. The total harmonic output is

$$P_{h,\mathrm{tot}} = P_{h,2}\bigl(P_{h,1}(T_1), \, T_2\bigr)$$

Taking the derivative with respect to $T_1$:

$$\frac{\partial P_{h,\mathrm{tot}}}{\partial T_1} = \underbrace{\frac{\partial P_{h,2}}{\partial P_{h,1}}}_{> 0} \times \underbrace{\frac{\mathrm d P_{h,1}}{\mathrm d T_1}}_{= 0 \text{ at optimum}} + \underbrace{\frac{\partial P_{h,2}}{\partial T_2}}_{= 0 \text{ at optimum}} \times \underbrace{\frac{\mathrm d T_2^*}{\mathrm d T_1}}_{\text{whatever}}$$

The second term vanishes because $T_2^*$ is already the optimum for stage 2 (its own derivative is zero). The first term vanishes because $\mathrm d P_{h,1}/\mathrm d T_1 = 0$ at the stage-1 optimum. Therefore the cascade-optimum condition reduces to independently impedance-matching each stage.

This holds exactly, not just in the small-signal limit.

## 3. Visualising the factorisation¶

We sweep $T_1$ and $T_2$ on a grid and colour the total harmonic output. The maximum sits exactly at the independently-optimised values.

In [6]:

T1_grid = np.linspace(0.005, 0.08, 80)
T2_grid = np.linspace(0.01, 0.15, 80)
P_tot = np.zeros((len(T2_grid), len(T1_grid)))

for i, T2 in enumerate(T2_grid):
    for j, T1 in enumerate(T1_grid):
        stages = [
            Stage(s1["loss_per_pass"], s1["gamma_shg"], T1),
            Stage(s2["loss_per_pass"], s2["gamma_shg"], T2),
        ]
        P_tot[i, j] = cascade_output(P_in, stages, [eta_t])["total_harmonic_W"]

fig, ax = plt.subplots(figsize=(7, 5.5))
im = ax.contourf(T1_grid * 100, T2_grid * 100, P_tot, levels=20, cmap="viridis")
ax.plot(
    [opt_stages[0].T_IC * 100],
    [opt_stages[1].T_IC * 100],
    "r*",
    ms=14,
    label="Independent optima",
)
ax.set_xlabel("Stage-1 transmission  $T_1$ (%)")
ax.set_ylabel("Stage-2 transmission  $T_2$ (%)")
ax.set_title("Total harmonic output (W) — 2-D sweep")
fig.colorbar(im, ax=ax, label=r"$P_{h,\mathrm{tot}}$ (W)")
ax.legend(loc="lower right")
fig.tight_layout()

No description has been provided for this image

Take-away. The red star (independent optima) sits exactly on the ridge of the landscape. There is no coupled optimum to search for — you simply match each stage to its own input power.

## 4. Applying the model to measured stages¶

Updated 2026-09-10 (RC-07). The former Friedenauer comparison used the incorrect SHG normalization and assumed passive loss L=T_IC. Its agreement at one BBO output did not validate the material constants. Nonlinear impedance matching gives T=L+(1-L)η; coupler transmission therefore cannot be substituted for passive loss.

The dated recalculation compares fixed-coupler outputs, independently optimized stages, and losses fitted to the reported operating points. It separates holding losses fixed from refitting them after the γ correction. Fitting the same output you later reproduce is calibration, not a validation test. UV extraction and inter-stage transport also need explicit assumptions.

## 5. Try this¶

Edit parameter_overrides (or the local 04-params.yaml) and experiment:

- Make stage 1 much stronger than stage 2 (swap γ values). Does the overall efficiency change? (Hint: the bottleneck is usually the downstream stage because it sees less power.)
- Reduce the transport efficiency to 0.50 (a poorly mode-matched relay). How much does the overall efficiency drop?
- Add a third stage with γ = 0.1 W⁻¹. What T_IC does the optimiser choose, and what is the three-stage overall efficiency?

In [7]:

print("Tutorial 04 complete.")

Tutorial 04 complete.

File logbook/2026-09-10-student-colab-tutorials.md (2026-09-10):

# Student tutorials with Google Colab access

**Date:** 2026-09-10\
**Steward:** Ulrich Warring\
**Status:** Student entry point implemented; four notebooks pass fresh-runtime checks.\
**Baseline:** `3466c3262aa72af93f10a3699c48782d401548f8`

## Charter §9 triggers

- Affects Level 0 parameters? No.
- Affects Level 1 parameters? No.
- Affects success criteria or gate state? No.

## What changed

The [tutorial index](../docs/tutorials/index.md) now introduces the existing
four notebooks to students, with an Open in Colab link for each, a reading
order, one guided exercise per notebook, and routes to contribute a saved
notebook, issue or pull request. Local installation is optional. The obsolete
1.5% cascade-validation claim is removed from the index and replaced by the
current calibration/validation distinction. The cascade’s old fixed percentage
summary is replaced by power accounting at the calculated operating points;
this identity does not require weak depletion or matched couplers. Coupler
sensitivity prose now refers to the actual sweep instead of promising fixed
percentage errors.

Each canonical tutorial source includes a setup cell. Outside a project
checkout it clones the public repository into a temporary runtime directory,
checks out reviewed revision `3466c32`, installs that revision's declared
packages with the kernel's Python, and locates its source and YAML inputs.
An existing local checkout uses its own code. No Drive mount or accelerator
is required. Runtime package versions are not pinned by this bootstrap;
the source/input pin and environment versions are separate provenance facts.

Each notebook also provides `parameter_overrides`, applied after loading the
YAML defaults. Students can save parameter changes inside their notebook
instead of relying on files that disappear with a Colab runtime. The guide
explains saving a copy and downloading work. The setup and override cells
are retained in the published `.ipynb` files, not only in the HTML.

The README and landing page identify the student guide. Existing software
licensing is retained; the licence map records the tutorial narrative/output
assignment question under D6. This publication does not adopt new optical
specifications or clear D1/D2.

**Pin maintenance owner: Ulrich Warring.** Dependency-aware CI enforcement
is assigned to [RC-06](2026-09-09-repository-review-task-card.md#rc-06--next--make-scientific-checks-and-toolchain-enforcement-reproducible).
Changes to the runtime code, defaults or installation inputs require a
reviewed update of the four pins or a dated decision to retain the earlier
teaching baseline. A pin update requires the opt-in runtime check, regenerated
tutorials and refreshed manifests. Unrelated documentation changes do not
require a bump; the model revision is separate from the publication commit.

## Validation

- All four tutorials execute through the normal render pipeline. Their
  saved numerical outputs and eight embedded figures are exactly unchanged
  from the baseline. All eight notebook/HTML files reproduce byte-for-byte
  on a second render.
- [The opt-in runtime check](../scripts/check_colab_tutorials.py) creates a
  temporary virtual environment, installs ipykernel, and runs each notebook
  in a fresh kernel outside any checkout. All four fetch the pinned revision,
  install their dependencies and complete successfully. Assertions verify
  that the imported code belongs to the fetched checkout at the expected
  revision, and that the example parameter override takes effect.
- The tested environment resolves to Python 3.13.7, NumPy 2.5.3 and SciPy
  1.18.1. Its eight figure PNGs exactly match the published local renders.
- The four Colab URLs target valid committed notebook paths. Local guide
  links and front matter validate. Scoped Black/isort/Ruff checks pass for
  the new runtime checker; no `/src/` or core-test implementation changes.
- The RC-07 manifest is refreshed because it records tutorial 4's source and
  generated outputs. RC-07 numerical results remain unchanged. Earlier
  manifests remain recoverable at their recorded commits.

Reproduce the runtime check from the repository root using the existing
notebook environment; it downloads public code and packages:

```sh
.venv/bin/python scripts/check_colab_tutorials.py
.venv/bin/python scripts/render_tutorials.py
.venv/bin/python -m scripts.review.rc07_manifest > data/review/2026-09-10/manifest.json
```

This is a local test of the fresh-runtime execution path, not a claim of
execution on Google's hosted service. Browser control was unavailable in
this session, so a signed-in Colab run remains a separate end-user check.
Google's [Colab FAQ](https://research.google.com/colaboratory/faq.html) documents
loading GitHub notebooks, saving copies and runtime persistence.

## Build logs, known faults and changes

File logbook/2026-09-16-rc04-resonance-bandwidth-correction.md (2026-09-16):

# RC-04: a loaded piezo resonance is not a lock bandwidth

**Date:** 2026-09-16\
**Steward:** Ulrich Warring\
**Licence:** CC-BY-NC-SA-4.0 — logbook entries are Sail per [`logbook/LICENSE.md`](LICENSE.md). This entry is not added to the explicit `LICENSES.md` rows used for the SHG catalogue records; the folder declaration governs it.\
**Starting revision:** `f75120e`\
**Status:** Corrections published and live-verified; the RC-04 package remains open.

## Charter §9 triggers

- Affects Level 0 parameters? No.
- Affects Level 1 parameters? No. The Level-1 seed frequency-noise constraint keeps its existing definition and numerical budget; only an unsupported bandwidth attribution is withdrawn.
- Affects success criteria or gate state? No.

G1 and G2 remain OPEN. G3 remains CLOSED (2026-05-01). No simulation code, numerical parameter value, measurement record or drawing artefact changed; nothing was added to `/src/`. This is a withdrawal of an unsupported claim, not a relaxation of a constraint.

## What prompted this

The [cavity-lock electronics record](2026-09-15-shg-cavity-lock-electronics.md) corrected the resonance-versus-bandwidth confusion on the catalogue, photo survey, baseline and seed-laser pages. A repository-wide check found the same equation in six further artefacts, including the machine-readable extraction that those corrected pages cite. RC-04's third bullet asks for exactly this distinction.

## Source check

The publisher PDF (local, uncommitted copy) was read for §3, printed p. 372. The paper states:

- "The second mirror, highly reflective (M2, R > 99.98%), is mounted on a small stacked piezo with high resonance frequency (Thorlabs model AE020304D04, ν_res ≈ 18 kHz loaded)."
- "We glued the piezo to a disk made of lead to absorb vibrations and reduce the resonance frequency of the mirror mount."
- "The dimension of this mirror is very small, allowing for a high servo bandwidth (3 × 3 × 2 mm³)."

The error signal reaches "a proportional-integral-derivative (PID) servo and after amplification (HV amp) is fed to the piezo (PZT) on which the mirror M2 is mounted."

So 18 kHz is a **loaded piezo resonance**. The paper reports **no** measured servo, unity-gain or closed-loop bandwidth, and links the mirror's small dimension to "a high servo bandwidth" only qualitatively. Note also that the lead disk *reduces* the mirror-mount resonance, so the loaded piezo figure is not itself the mount's resonance.

## Changes

| Artefact | Before | After |
|---|---|---|
| [`Friedenauer2006/extracted.yaml`](../data/literature/Friedenauer2006/extracted.yaml) `LBO_M2_piezo_resonance_loaded` | note: "bounds the achievable Hänsch-Couillaud servo bandwidth" | paper quotation with printed page; inference explicitly withdrawn; value unchanged at 1.8e4 Hz |
| [`Friedenauer2006/notes.md`](../data/literature/Friedenauer2006/notes.md) extraction log | "≈ 18 kHz (bounds the achievable servo bandwidth)" | dated correction; gloss withdrawn |
| [`docs/hardware-status.md`](../docs/hardware-status.md) | "above the ~18 kHz doubling-cavity lock bandwidth" | servo band named; loop bandwidth marked unmeasured, with a pointer to the electronics section |
| [`docs/architectures/requirements.md`](../docs/architectures/requirements.md) `REQ-NG-003` | "the SHG-cavity locking bandwidth (~ 18 kHz loaded piezo per [Frie06])" | servo response cited; bandwidth marked unmeasured; resonance identified as such |
| [`docs/tutorials/vecsel-systems.md`](../docs/tutorials/vecsel-systems.md) §3 Coastline label | "(~18 kHz lock bandwidth)" | parenthetical removed; the transfer-function statement stands unchanged |
| [`docs/assets/vecsel-linewidth-conversion.svg`](../docs/assets/vecsel-linewidth-conversion.svg) | "lock bandwidth ≈ 18 kHz"; "tracks out seed FM below ≈ 18 kHz"; footnote naming 18 kHz | "closed-loop bandwidth unmeasured"; tracking described relative to the loop bandwidth; footnote drops the number |
| [`repository review task card`](2026-09-09-repository-review-task-card.md) RC-04 | progress recorded to 2026-09-10 | dated 2026-09-16 progress block; remaining scope listed |

The numerical value ≈ 18 kHz is retained everywhere it appears. Only its interpretation changed.

## What remains open in RC-04

- [`constraints/phase-noise-budget.md`](../constraints/phase-noise-budget.md) and [`bc-g-results.md`](2026-05-20-bbo-coating-run-wp/bc-g-results.md) still carry their own servo-bandwidth wording; `bc-g-results.md` §E cites a "Friedenauer loaded-resonance / HC-bandwidth anchor (~18 kHz)". Both are dated work-package records; their reconciliation is RC-04 acceptance work, not a silent edit.
- The four-document cross-reference table, the harmonic-phase and path-length checks, and the unavailable measurement evidence are unchanged and still required.
- `requirements.md` `REQ-NG-003` still describes its task as bounding the "SHG-cavity-locking-bandwidth-to-amplitude-noise transfer". That wording presumes a loop bandwidth exists but assigns it no value; reviewed and left as is.
- No closed-loop bandwidth has been measured for any in-house doubling cavity. That measurement remains the only route to a supported number.
- `vecsel-linewidth-conversion.svg` is referenced by no page in the repository, though it is still published under `docs/assets/`. Its removal or reuse is a steward decision; it was corrected rather than deleted.

## Validation

- `.venv/bin/python -m pytest -q`: **275 passed, 3 skipped**. The skips are the block-audit regeneration and two viewport/proxy tests that need ezdxf, absent from the standard environment. No test covers this prose.
- `git diff --check` passes.
- The rewritten SVG parses as XML. Publication review with macOS Quick Look found the revised footnote clipped at the left edge; that sentence was wrapped onto two lines without changing its wording. The diagram geometry and colours are unchanged.
- Publication review also confirmed that the parsed extraction differs from the previous revision only in the intended note, with the value and units preserved at 1.8e4 Hz. Every relative link in this entry and the task card's link to it resolves.
- Implementation checks above were supplied with the handoff; publication review did not repeat the full suite for the footnote wrap and logbook updates.

## Publication verification

Correction commit `4589d20fe748e8714dd719302eef391b639b4540` was pushed to
`main`. GitHub Pages reports that exact commit **built**, with no error,
at 2026-09-16 05:55:25 UTC.

Public HTTP checks confirm the corrected wording on
[hardware status](https://uwarring82.github.io/mg-plus-uv-chain/hardware-status.html),
[requirements](https://uwarring82.github.io/mg-plus-uv-chain/architectures/requirements.html)
and the [VECSEL tutorial](https://uwarring82.github.io/mg-plus-uv-chain/tutorials/vecsel-systems.html).
The hardware-status pointer resolves to the existing planned-electronics
section. The published SVG, raw extraction, review task card and correction
entry match the committed local bytes. The public extraction still gives
`LBO_M2_piezo_resonance_loaded` as 1.8e4 Hz. These are content and publication
checks, not laboratory validation or closure of RC-04.

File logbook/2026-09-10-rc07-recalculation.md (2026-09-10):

# RC-07 — Cascade, fitted loss and coating-target recalculation

**Date:** 2026-09-10  
**Steward:** Ulrich Warring  
**Baseline:** `4404074d5114ecf7515a2cbd71910c16c036359d`  
**Status:** Recalculation and conditional impact assessment filed. D1 acceptance, material/loss measurements and any D4 specification amendment remain open.  
**Scope:** [RC-07](2026-09-09-repository-review-task-card.md#rc-07--next--recalculate-affected-results-and-revise-their-claims), following the [numerical foundations](2026-09-09-numerical-foundations.md).

## Charter §9 trigger questions

- **Affects Level 0 parameters?** No; locked Raman parameters are unchanged.
- **Affects Level 1 parameters?** No binding value is amended. This report calculates the implications for the historical May coating targets and records what needs disposition.
- **Affects success criteria?** No.
- **Changes Charter, gate state or prior sign-off?** No. No D1 acceptance is inferred from the corroborating checks or instruction to continue the calculations.

## Result and interpretation

Correcting γ while keeping the old BBO loss predicts **228.872 mW**, compared
with the published 275 mW at 0.95 W input and T=0.016. Refitting loss to that
same point reduces it from the May **15,288 ppm** to **13,191 ppm**. Under the
May assumptions for transferring this loss budget to the new build, the
single-variant equal-penalty IC centre moves from **1.9965% to 1.6841%**.

At the 1.5 W design input, refitting restores almost the same predicted UV
output, but circulating power rises **18.5%**, from **65.37 to 77.49 W**.
The approximately unchanged UV output therefore does not preserve the old
visible-light coating-intensity margins. None of these fitted quantities is
an independent measurement of the new cavity or the received Agile mirrors.

## Inputs and comparisons

The [new analysis source](../notebooks/exploration/2026-09-10-rc07-recalculation.py)
reads the same [Friedenauer extraction](../data/literature/Friedenauer2006/extracted.yaml)
as the May diagnostic. Crystal lengths, reported waists, input powers,
reported harmonic powers, coupler reflectivities and LBO d_eff are unchanged.
The main comparison deliberately retains the diagnostic's material inputs:
LBO indices 1.605/1.620, BBO indices 1.67276/1.565, BBO walk-off 83.1 mrad,
and BBO d_eff=1.44 pm/V, bracketed by 1.30–1.60 pm/V. These choices isolate
the code correction; they are not new Sellmeier or nonlinear-coefficient
measurements. The index limitations below remain material.

The old SHG normalization is reconstructed algebraically: evaluating the
corrected kernel at B√ξ restores the old missing-ξ kernel, and multiplying
corrected K by n₁ restores the old missing-index prefactor. Both sides use
the corrected cavity solver. This isolates the SHG change; it is not a
reproduction of the old solver's invalid-domain behaviour. The reconstructed
BBO γ is 1.491391914×10⁻⁴ W⁻¹, consistent with the rounded May pin
1.4914×10⁻⁴. The coating comparison uses the **actual rounded May pins**.

| Quantity | Old normalization | Corrected normalization |
|---|---:|---:|
| LBO γ (W⁻¹) | 3.56026136×10⁻⁴ | 2.21823138×10⁻⁴ |
| BBO γ, central (W⁻¹) | 1.49139191×10⁻⁴ | 1.05865670×10⁻⁴ |
| BBO γ, d_eff low/high (W⁻¹), corrected | — | 8.62813379×10⁻⁵ / 1.30698358×10⁻⁴ |
| BBO hₘ at the reported 19.4 µm waist | ≈0.03305 | 0.03924309675 |
| BBO optimum waist with retained inputs | historical ≈42 µm | 19.3456934 µm |

The small difference from yesterday's hₘ=0.03924301048 is from evaluating
ξ and B from the full geometry rather than rounded diagnostic anchors
ξ=1.41317, B=18.0166. It is not another normalization change.

The May BK notebook is re-executed with corrected explanatory text. Its
≈42 µm discrepancy and inferred ≈2.5 mrad effective walk-off are superseded.
The LBO waist discrepancy remains an input/geometry question; it is not
assigned solely to refractive-index uncertainty without a verified
operating-temperature Sellmeier calculation.

## Cascade and fitted loss

For a nonlinear cavity, impedance matching is T=L+(1−L)η. Consequently,
setting passive loss L equal to the paper's T does not follow from a claim
that the coupler was impedance matched. The original diagnostic also mixed
separately optimized per-stage outputs with a fixed-coupler cascade summary.
The new calculation keeps those operating points separate.

The following retains the original **comparison assumption L=T**; these
losses are not measured. Stage powers use their reported input powers:
1.80 W for LBO and 0.95 W for BBO.

| Prediction | Old normalization | Corrected normalization |
|---|---:|---:|
| LBO at reported T=0.025 | 0.648004 W | 0.530296 W |
| LBO, T optimized at the same assumed L | 0.701753 W | 0.556772 W |
| BBO at reported T=0.016 | 0.259917 W | 0.215167 W |
| BBO, T optimized at the same assumed L | 0.270933 W | 0.221121 W |
| Cascaded UV, both reported couplers | 0.143327 W | 0.0820418 W |
| Cascaded UV, both couplers optimized | 0.167435 W | 0.0903407 W |

Cascade transport is assumed one, as in the original diagnostic. The
reported equal 0.95 W values at the LBO output and BBO input are not an
independent, precise relay-throughput measurement.

Next, fit L **at each actual reported coupler**, holding γ fixed, to match
0.950 W LBO output and 0.275 W BBO output. The solve is

$$
\epsilon_{\rm ext}\,P_h(P_{\rm in},T,L,\gamma)=P_{\rm measured}.
$$

The main comparison assumes ε_ext=1 and no UV feedback. Generated harmonic
power, extracted power and power delivered onward coincide only under these
assumptions. The fit rejects unattainable output values; endpoint agreement
within 3×10⁻¹² relative output is treated as numerical equivalence to the
physical boundary, consistent with the forward solver's tolerance.

| Fitted result | Old normalization | Corrected normalization |
|---|---:|---:|
| LBO passive loss | 15,840.59 ppm | 13,059.29 ppm |
| LBO matched T at the reported input | 3.41044% | 2.73358% |
| BBO passive loss | 15,287.57 ppm | 13,191.25 ppm |
| BBO matched T at the reported input | 2.16915% | 1.85283% |
| Cascade at reported couplers | 0.275000 W | 0.275000 W |
| Cascade with both couplers optimized | 0.298532 W | 0.278446 W |

The equal 275 mW entries are **calibration closure**. They do not validate
material constants, establish ±1.5% uncertainty in γ, or demonstrate that
Friedenauer actually had these passive losses. Independent circulating-power,
linear-cavity loss, mode-matching and extraction measurements are needed to
separate those quantities. Optimizing the fitted cascade is a conditional
extrapolation away from the calibration point.

## Coating comparison at the May default budget

The May construction subtracts a **3,400 ppm mirror-loss envelope** from the
fitted total loss, then adds a **1,500 ppm proposed mirror budget**. We retain
that additive construction for direct comparison. Three cases distinguish
normalization from recalibration:

| Case | γ (W⁻¹) | Reference total loss | Residual called “non-mirror” in May | New-build default total loss |
|---|---:|---:|---:|---:|
| Frozen May inputs | 1.4914×10⁻⁴ | 15,288 ppm | 11,888 ppm | 13,388 ppm |
| Corrected γ, old loss fixed | 1.05865670×10⁻⁴ | 15,288 ppm | 11,888 ppm | 13,388 ppm |
| Corrected γ, refitted loss | 1.05865670×10⁻⁴ | 13,191.25 ppm | 9,791.25 ppm | 11,291.25 ppm |

The residual is a **model-dependent allocation**, not a measured
non-mirror loss. The R floors bound non-reflected power; they do not measure
transmission alone or determine the actual mirror contribution. Transferring
the residual unchanged to a different crystal, oven and cavity is another
assumption.

| Case | Input | T optimum | Circulating power | Generated UV | Worst penalty at historical 1.9965% ±0.05 pp |
|---|---:|---:|---:|---:|---:|
| Frozen May | 0.5 W | 1.7565% | 28.466 W | 0.12051 W | 0.970% |
| Frozen May | 1.5 W | 2.2945% | 65.373 W | 0.63326 W | 0.946% |
| Corrected γ, old loss | 0.5 W | 1.6539% | 30.232 W | 0.09655 W | 1.952% |
| Corrected γ, old loss | 1.5 W | 2.0861% | 71.906 W | 0.54461 W | 0.178% |
| Corrected γ, refitted loss | 0.5 W | 1.4815% | 33.749 W | 0.12029 W | 4.317% |
| Corrected γ, refitted loss | 1.5 W | 1.9358% | 77.488 W | 0.63220 W | 0.112% |

Each penalty is relative to that row's own optimum. The equal-relative-penalty
centre across the two pump scenarios is **1.996472% / 1.849107% / 1.684123%**
for the three cases, respectively. The corrected/refitted centre costs
0.6796% at either scenario endpoint before manufacturing tolerance.
The full JSON includes all eight scenario/loss-grid rows per case and
±500 ppm, ±1,000 ppm, ±0.5 pp and ±1 pp tolerance sweeps.

### Sensitivities rather than confidence intervals

Jointly refit loss whenever d_eff or extraction changes. Treating γ and its
fitted L as independent error bars would discard their calibration correlation.

| d_eff | Assumed UV extraction | Refit BBO loss | Default equal-penalty T |
|---|---:|---:|---:|
| 1.30 pm/V | 100% | 11,985 ppm | 1.5126% |
| 1.30 pm/V | 95% | 11,440 ppm | 1.4708% |
| 1.44 pm/V | 100% | 13,191 ppm | 1.6841% |
| 1.44 pm/V | 95% | 12,610 ppm | 1.6395% |
| 1.60 pm/V | 100% | 14,469 ppm | 1.8723% |
| 1.60 pm/V | 95% | 13,849 ppm | 1.8247% |

The 95% extraction row is a hypothetical **whole-path** efficiency, not a
claim that a front-face T floor, an AR reflectivity or the Agile reports
establish that number. Multiply each sensitivity row's generated UV by its
assumed extraction to obtain external UV power. Residual mode mismatch and
pump entrance losses are still absorbed into this simplified calibration.

Two further effects are recorded separately, not combined into a statistical band:

- At central d_eff, assigning **0 / 1,500 / 3,400 ppm** of the fitted old
  total to mirrors gives default centres **1.9545% / 1.8334% / 1.6841%**.
  These are loss-allocation scenarios, not measured mirror losses. They show
  why subtracting the R-floor envelope does not uniquely predict a new-build T.
- The harmonic index **1.565 is approximate and is not a verified angular
  effective index at phase match**. The relation Δk=2k₁−k₂ implies
  n₂,eff=n₁ at collinear wave-vector match; the optimized Gouy mismatch adds
  a small correction. A sensitivity using n₂=1.67276 gives
  γ=9.90458×10⁻⁵ W⁻¹, fitted loss 12,794.86 ppm and centre **1.6271%**.
  This is not a new Sellmeier extraction or an acceptance of that simplified
  operating point. LBO operating-temperature indices also remain unresolved.

The cavity model multiplies round-trip survival factors. Using products for
0.0007/0.0007/0.002 old mirror losses and 0.0003/0.0003/0.0009 new losses,
then refitting the residual survival, gives a new total **11,312.55 ppm**
and centre **1.68577%**, versus the additive 11,291.25 ppm / 1.68412%.
This small composition correction is far below the unmeasured loss-allocation
and material sensitivities; both constructions are retained in the output.

## Intensity and specification impact

At the default budget and 1.5 W input, the spherical Gaussian approximation
uses w₀=19.4 µm and a curved-mirror radius **254.702 µm**, from propagation
through 5 mm of BBO, q_air=q_BBO/n at a flat exit, then 24.7 mm of air.
These are beam-normal Gaussian peak intensities 2P/(πw²). Brewster-surface
and oblique-mirror astigmatism, actual long-arm positions and layer fields
are not solved here. Taking the pre-conversion circulating power at every
fundamental mirror gives a conservative power proxy within this model.

| Proxy at 1.5 W | Frozen May | Corrected γ, refitted loss |
|---|---:|---:|
| BBO waist, green peak | 11.058 MW/cm² | 13.107 MW/cm² |
| Curved mirror, green peak | 64.153 kW/cm² | 76.042 kW/cm² |
| Plane mirror, assuming w=200–150 µm | 104.05–184.97 kW/cm² | 123.33–219.25 kW/cm² |
| UV peak **if its radius equals the green curved-mirror radius** | 621.44 W/cm² | 620.40 W/cm² |

The last row is deliberately conditional: the generated UV spatial mode and
walk-off profile are not established by the fundamental spot calculation.
It cannot validate a coating-lifetime estimate or a per-surface UV margin.

| Historical May item | Consequence / disposition |
|---|---|
| M1 centre 19,965±500 ppm and ≈1% worst-case penalty | Central refit predicts up to **4.32%** low-scenario penalty in that historical band; new centre is conditional on the unresolved inputs above. Record for D4; do not silently replace the supplier target. |
| “Higher R is never a failure mode” in M1 notes | Not a general model result: lower T can increase mismatch and T=0 admits no pump. Acceptance must use the actual operating point and required output, not monotonic preference for R. |
| M2/M3/M4 loss allocation 300/300/900 ppm | Unchanged historical targets. The model does not independently validate their allocation or prove new-build non-mirror loss equals the fitted residual. |
| M1/M2 visible LIDT margin | Green intensity proxy rises 18.5%. At a requested 500 kW/cm² threshold, the ratio to the plane-mirror worst proxy falls from ≈2.70 to ≈2.28; this is a requested-threshold ratio, not a measured damage margin. |
| M3/M4 visible LIDT margin | For the M4 requested 250 kW/cm² threshold, the ratio changes from ≈3.90 to ≈3.29. No threshold or service-life requirement is relaxed. |
| M4 UV transmission, back-face AR and UV LIDT | Require whole-path extraction and UV spot evidence; a nearly unchanged generated-power proxy does not validate lifetime or simultaneous-wavelength damage margins. |
| Geometry, quantity and received Agile stock | No new evidence here changes geometry or receipt facts. No supplier defect is inferred from a model correction. |

Dated notices in the work package and sheets link here while preserving
historical fields and sign-offs. The public coating explainer corrects the
missing k₁ and factor of two in b, and distinguishes its historical tables
from the current calculation. No new coating specification is adopted.

## Reproduction and evidence

The [results JSON](../data/review/2026-09-10/rc07-results.json) stores full-precision
inputs, cases, sensitivity grids, environment and input hashes. The
[output manifest](../data/review/2026-09-10/manifest.json) maps the edited
notebooks, renderer, data and HTML/notebook artifacts to this baseline and
records printed outputs. The [recorded environment](../data/review/2026-09-09/environment.txt)
from the preceding correction is reused: Python 3.13.7, NumPy 2.5.3, SciPy
1.18.1 and pytest 9.1.1. No new dependency is needed.

```sh
PYTHONPATH=. MPLBACKEND=Agg .venv/bin/python notebooks/exploration/2026-09-10-rc07-recalculation.py
.venv/bin/python -m scripts.review.render_rc07
.venv/bin/python scripts/render_tutorials.py 04
.venv/bin/python -m scripts.review.rc07_manifest > data/review/2026-09-10/manifest.json
.venv/bin/python -m pytest --cov=src --cov-report=term-missing -q
```

**261 tests pass; source coverage is 96.18% including branches.** Nine new
analysis tests recover passive loss from an independently constructed field
balance (including zero-loss and non-unit extraction), reject unattainable
fits and invalid extraction, and compare the equal-penalty solution with a
1,001-point independent transmission scan. No `/src/` implementation or
locked parameter changes in this set. Scoped Black/isort/Ruff checks cover
the new analysis, tests and modified rendering code; this is not RC-06's
repository-wide lint/type/CI completion.

All five rendered notebook/HTML pairs are byte-identical on a second run,
as is the results JSON; the comparison includes the complete output file
inventory, including newly generated files. All five embedded figures were
visually inspected. Executed notebooks contain no error or stderr outputs.

The three historical notebooks are re-executed with dated context; the
May IC sweep deliberately replays its frozen inputs. A fourth notebook
contains the current comparisons. Tutorial 4 removes the obsolete numerical
parable and its claim that one BBO agreement validates the material constants.
A successful historical replay is not acceptance of historical physics.

### Follow-up — test isolation and discoverability

The initial tests loaded the exploratory notebook with `runpy.run_path` at
collection time, using a working-directory-relative path. The two generic
functions now live in [cavity_fits.py](../scripts/review/cavity_fits.py), imported
directly by both the notebook and tests. They contain no material presets,
data loading or plotting imports. The notebook retains all architecture-specific
scenarios and its pre-G1 marker; nothing is promoted into `/src/`.

All 261 tests pass when launched from `tests/`. A separate full-suite
`--collect-only` check also passes with matplotlib imports and execution of
code under `notebooks/` explicitly blocked. The numerical function bodies are
unchanged, and the regenerated results match the prior JSON exactly except
for source hashes. The affected notebook/HTML pair and JSON reproduce
byte-for-byte on repeat rendering. Both provenance records include the new
helper; the original record remains available at `d11a76f`.

The landing page now links directly to the numerical review index. These
changes address test isolation and navigation, without changing the scientific
dispositions above. For coverage runs outside the repository root, specify
`--cov-config=../pyproject.toml` from `tests/` to retain branch coverage and the
configured threshold; pytest's own root-relative import configuration already
works from either directory.

**Remaining work:** D1 steward acceptance; independent loss/mode-matching,
whole-path extraction, angular/temperature-dependent index and beam-profile
checks; then D4 disposition of any replacement procurement targets. D2 and
the Raman/noise branches of RC-07 remain separate. This report completes the
stated conditional SHG/cascade recalculation, not hardware validation or the
entire repository review.

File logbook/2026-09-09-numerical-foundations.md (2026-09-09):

# Numerical foundations — RC-01 / RC-05, with RC-02 decision inputs

**Date:** 2026-09-09  
**Steward:** Ulrich Warring  
**Baseline:** `9a498165532e029e1ba0706d380f760402dd7584`  
**Status:** Generic corrections implemented and tested; D1 evidence filed for review. RC-02/D2 and the wider RC-07 impact assessment remain open.  
**Task:** [Repository review card](2026-09-09-repository-review-task-card.md).

## Charter §9 trigger questions

- **Affects Level 0 parameters?** No: locked parameters and Raman values are unchanged.
- **Affects Level 1 parameters?** No binding requirement is amended. Revised SHG calculations require a later impact assessment before changing coating targets.
- **Affects success criteria?** No.
- **Changes Charter text or gate state?** No.

## RC-01: conventions and independent calculations

For the centred, lossless case, [Daniel, Tsai & Hemmerling (2020), Eqs. (1)–(3)](https://arxiv.org/abs/2009.08430) give

$$
P_2=K L k_1 h P_1^2,\qquad
K=\frac{2\omega_1^2 d_{\rm eff}^2}{\pi\epsilon_0c^3 n_1^2 n_2},
\quad k_1=2\pi n_1/\lambda_{\rm vac},\quad b=k_1w_0^2,
$$

and, with $\xi=L/b$, $B=\rho\sqrt{Lk_1}/2$, $\sigma=b(2k_1-k_2)/2$,

$$
h=\frac{1}{4\xi}\int_{-\xi}^{\xi}\!\int_{-\xi}^{\xi}
\frac{e^{i\sigma(\tau-\tau')}e^{-B^2(\tau-\tau')^2/\xi}}
{(1+i\tau)(1-i\tau')}\,d\tau\,d\tau'.
$$

The old code omitted `/xi` in the walk-off exponential and one `n_omega`
in K's denominator. Since Lk₁ is dimensionless, **K has units W⁻¹**.
The production code now evaluates the reduced one-dimensional Eq. (3).
The [independent reference](../scripts/review/shg_reference.py) instead uses
tensor Gauss–Legendre quadrature of Eq. (2), without importing production BK code.
Six comparisons span ξ=0.2–4 and B=0–18.0166. Refining 256×256 to 512×512
nodes and comparing the two methods gives relative differences below 10⁻¹²
in this set; regression tolerances are 2×10⁻⁸ relative / 10⁻¹⁰ absolute.
This establishes convergence at these inputs, not every possible input.

**Independent absolute normalization:** the test integrates the generated
plane-wave intensity radially over a weakly focused Gaussian pump. Using
physical peak fields, $I_j=n_j\epsilon_0c|E_j|^2/2$ and the undepleted
coupled-wave equation $dE_2/dz=i\omega_1d_{\rm eff}E_1^2/(n_2c)$, the
Gaussian intensity $I_1(r)=2P_1e^{-2r^2/w_0^2}/(\pi w_0^2)$ gives

$$
P_2/P_1^2\longrightarrow
\frac{2\omega_1^2d_{\rm eff}^2L^2}{\pi\epsilon_0c^3n_1^2n_2w_0^2}.
$$

The regression obtains this through numerical radial integration and compares
it with the public γ function at small ξ, for two different index pairs.
It does not call K to construct its expected answer (relative tolerance 10⁻⁹).
This is an undepleted, paraxial model with a fixed Gaussian pump.
The effective tanh² depletion law is not an exact focused-propagation solution.

### Absorption and focus position

The following is an explicit extension of the cited lossless integral, derived
here; Daniel et al. do not supply this absorbing-crystal formula. Let
`s=z/L`, `mu=2*z_focus/L-1`, and let α₁, α₂ be **intensity** absorption
coefficients. Then

$$
\tau(s)=2\xi s-\xi(1+\mu),\qquad
A(s)=\exp[-(\alpha_1L)s-(\alpha_2L)(1-s)/2].
$$

The pump field decays as exp(−α₁z/2), so its squared field in the SHG source
decays as exp(−α₁z). Harmonic amplitude created at z then decays by
exp[−α₂(L−z)/2] before the exit. Multiply the lossless pair kernel by
A(s)A(s′) and integrate over s,s′∈[0,1], with normalization ξ.
Input power is at the entrance; output harmonic power is at the exit.
This also fixes the sign of the old focus-offset integration limits.

A single sum `(alpha1 + alpha2/2)*L/2` cannot recover both propagation weights.
The new keyword arguments are `alpha_omega_L=alpha1*L` and
`alpha_2omega_L=alpha2*L`. **Nonzero legacy `kappa` now raises ValueError**
with migration guidance; zero remains accepted. No production notebook in this
repository supplies nonzero κ. This is an intentional API restriction, not a
silent interpretation of ambiguous caller data.

Three weak-focus limits check pump-only, harmonic-only and α₁=α₂/2 absorption.
For $a=\alpha_1L-\alpha_2L/2$,

$$
\lim_{\xi\to0}h/\xi=
\left[e^{-\alpha_2L/2}(1-e^{-a})/a\right]^2,
$$

with the continuous a=0 limit. Four additional tests solve the complex
propagation ODE directly,

$$
q'(s)=\frac{e^{-\alpha_1Ls+i\sigma\tau(s)}}{1+i\tau(s)}
-\frac{\alpha_2L}{2}q(s),\quad q(0)=0,\quad h=\xi|q(1)|^2,
$$

for positive/negative focus offsets and separate pump/harmonic absorption.
ODE tolerances are 10⁻¹¹ relative / 10⁻¹³ absolute; agreement is tested at
2×10⁻⁹ relative. These ODE comparisons use B=0; lossless nonzero B is checked
separately by tensor quadrature.

### Phase optimization and diagnostic results

`sigma_bracket` now means strict finite bounds. The implementation samples
at least eight points per π/ξ phase lobe (at least 33 total), refines each
sampled local maximum, and compares the endpoints. Four cases are checked
against an independent 481-point tensor-quadrature scan over [−6,6], including
zero and strong walk-off. A narrow interval whose maximum is an endpoint is
also tested. This is evidence for the numerical search in the tested regime,
not a proof of a global maximum for arbitrary bounds. `h_m_optimum` remains a
bounded local search in ξ, assumes one focus maximum, and checks both endpoints.

| Diagnostic | Filed baseline | Corrected |
|---|---:|---:|
| hₘ at ξ=1.41317, B=18.0166 | 0.03304954854 | 0.03924301048 |
| Independent 512×512 tensor hₘ | — | 0.03924301048 |
| ξ optimum at that B | not re-evaluated here | 1.42111651 |
| Waist optimum, L=10 mm, λ=559 nm, n₁=1.67276 | not re-evaluated here | 19.3456938 µm |
| Combined γ correction at fixed inputs | 1 | 0.709844383 |

The index is the ordinary BBO index at vacuum 559 nm from Eimerl (1987),
Eq. (1)/Table II(a), transcribed in the [draft extraction](../data/literature/Eimerl1987/extracted.yaml).
Digits reproduce the existing diagnostic input, not measurement precision.
The γ ratio uses the recomputed baseline hₘ; it differs slightly from the
card's 0.7098345 estimate, which used rounded 0.033050 and 0.039243.
This resolves the normalization direction at fixed inputs. It does **not**
settle the direction of a refitted cavity loss or a revised coating target.

## RC-05: continuous model and physical brackets

`auto` now evaluates tanh² at all powers. Explicit `small` remains γP²,
clearly documented as an unbounded approximation valid for γP≪1. Invalid
regimes and negative/nonfinite inputs are rejected even on zero-input paths.

At impedance match, Pc=Pin/T. Substituting into the matching equation gives

$$
f(T)=T-L-(1-L)\tanh^2\sqrt{\gamma P_{\rm in}/T}=0.
$$

f increases with T, f(L)≤0 and f(1)≥0; at L=T=0 use the right-hand limit −1
for positive γPin. Exact bounds [L,1] replace artificial offsets that excluded
the passive-limit root. Zero-pump/zero-γ paths return L. Saturation may round
the answer to one. The circulating-power solver uses the passive field
buildup, rounded outward by eight machine epsilons to retain the bracket
at vanishing nonlinear loss, as an upper bound and solves in sqrt(Pc/Pin), avoiding a fixed absolute
tolerance in watts. Rationalizing `1-sqrt(survival)` avoids cancellation at
tiny transmission/loss. Brent uses relative tolerance 10⁻¹² and the smallest
positive float as its absolute tolerance.

| Regression | Before | After |
|---|---|---|
| Pin=10⁻⁸ W, L=0.01, γ=10⁻⁴ W⁻¹ | bracket failure | T=0.010000000099 |
| η(auto), γP=0.049999 / 0.05 | 0.049999 / 0.04837935515 | 0.04837841908 / 0.04837935515 |
| Relative jump using the review's samples | 3.3478% downward | smooth increase |
| Explicit small-signal P=2 W, γ=1 W⁻¹ | 4 W despite bounded docstring | 4 W, explicitly outside approximation validity |

The cavity model references Pc before conversion and applies passive loss
afterward; complete harmonic extraction is assumed. At match,
`Pin = Ph + L*(Pc-Ph)`. Off match, reflected power completes the same balance.
The old test used L*Pc and a loose 0.5% tolerance. The new checks include
reflection, use 3×10⁻¹² relative tolerance, and remove the output clamp.
A computed Ph can exceed Pin by numerical roundoff of order the root tolerance;
no physically significant excess is accepted by the tests.

## RC-02: inputs for D2, without changing locked values

Write δ=Δ/(2π) and f_R=Ω_R/(2π), both in Hz. Γ is the population decay
rate in s⁻¹, with the draft's Γ/(2π)=41 MHz. The draft's simplified relation is

$$
\Gamma_{sc}=\Gamma\Omega_R/(2\Delta)=\Gamma f_R/(2\delta),\quad
 t_\pi=1/(2f_R),\quad N_{sc}=\Gamma/(4\delta).
$$

Only Ω_R/Δ changes frequency convention together; Γ remains the physical
decay rate. For the ideal, far-detuned equal-coupling Λ model, the eliminated
excited amplitude is proportional to `(Ω/(2Δ))*(c1+c2)`. On a resonant π
rotation starting in one ground state, c1=cos(Ω_R t/2), c2=−i sin(Ω_R t/2),
so |c1+c2|²=1 and Γ times the excited population gives the printed rate.
This conditional derivation does not establish the Mg⁺ Clebsch–Gordan factors,
polarization, multiple excited-state paths, branching or an actual gate error.

| Scenario | Printed-model rate (s⁻¹) | Recorded rate (s⁻¹) | Recorded/model | Model events/π pulse |
|---|---:|---:|---:|---:|
| Conservative | 161.0066235 | 2,500 | 15.5273115 | 0.0008050331 |
| Nominal | 1,288.052988 | 20,000 | 15.5273115 | 0.0016100662 |
| Aggressive | 8,587.019920 | 110,000 | 12.8100320 | 0.0042935100 |

The intensity convention also matters: a Gaussian beam with 1/e² intensity
radius w₀ has on-axis intensity **2P/(πw₀²)**. At fixed P this doubles the
single-level Ω_R relative to the draft's P/(πw₀²) convention, but does not
change the rate above at fixed target Ω_R and Δ. It cannot explain the split
recorded/model ratios.

D2 must choose prediction, upper limit or allowance for each recorded rate,
with its original rationale. If a prediction, replace it only after accepting
the atomic model and applicable §9 disposition. If a limit, preserve its
meaning and test an inequality; if an allowance, record scenario-specific
margins and their justification. No interpretation is selected here.

## Validation, outputs and remaining work

Baseline: Python 3.13.7 / NumPy 2.4.4 / SciPy 1.17.1 / pytest 9.0.3,
**142 tests passed**. A fresh `.venv` was then installed from the project's
`test,dev,notebooks` extras. Corrected full suite: **252 tests passed**,
**96.18% coverage including branches**. Resolved environment: Python 3.13.7,
NumPy 2.5.3, SciPy 1.18.1, pytest 9.1.1, recorded in
[environment.txt](../data/review/2026-09-09/environment.txt).
This snapshot supports reproducing this check; it does not select D5's
cross-platform support policy or complete RC-06's lockfile/CI work.

```sh
python3.13 -m venv .venv
.venv/bin/python -m pip install -r data/review/2026-09-09/environment.txt
.venv/bin/python -m pip install --no-deps -e .
.venv/bin/python -m pytest --cov=src --cov-report=term-missing -q
.venv/bin/python -m scripts.review.verify_numerical_foundations
.venv/bin/python scripts/render_tutorials.py
.venv/bin/python -m scripts.review.tutorial_manifest
```

The [numerical manifest](../data/review/2026-09-09/numerical-foundations.json)
records baseline revision, exact input hashes, conventions, environment and
unrounded results. Source and manifest are committed together; no uncommitted
input patch is required. The retained baseline comparison needs Git history
containing `9a49816`. Black/isort checks cover the three changed numerical
modules, their three test files, the renderer and review scripts. Ruff covers
the same paths with `N802` excepted for existing unit-bearing function names
such as `harmonic_output_W`; this is a scoped check, not a repository-wide
lint/type-cleanup claim. Type, schema, full link and CI checks remain RC-06/09.

All four tutorial pairs are regenerated. The renderer now creates a temporary
kernelspec using its own interpreter rather than a potentially unrelated user
`python3` kernel. Tutorial 1 corrects K's equation/units, distinguishes the
σ=0 analytic limit from optimized hₘ, and removes the auto-switch claim.
The [tutorial manifest](../data/review/2026-09-09/tutorials.json) maps source,
parameters, renderer, numerical modules, environment and all eight outputs,
with before/after printed numerical results. The first repeat-render check
failed: invalid Python string escapes produced warnings containing temporary
kernel paths. The source math-label strings are corrected (warnings are not
filtered). Inspection also found that the baseline notebooks contained **no
embedded plot outputs**: the renderer forced plain Agg. It now selects the
headless inline backend so the tutorial figures are actually included.
There is consequently no baseline rendered image for a pixel comparison.
All **eight figures** were inspected. The final unchanged repeat render produced
**zero differences across all eight HTML/notebook outputs**, checking both the
filename set and content hashes (including newly generated files). No warning
or error outputs remain in the executed notebooks. This verifies the artifacts,
not the full Jekyll site layout in a browser.

The calculations page now identifies the ≈42 µm interpretation as superseded.
The historical May notebook narratives, cascade/loss fits, IC sweep, coating
work package and uncertainty bands still require RC-07 recalculation and
impact assessment. Existing May specifications remain historical procurement
records; the 22 received Agile mirrors are not reclassified by a model change.

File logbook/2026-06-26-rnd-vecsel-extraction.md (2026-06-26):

# 2026-06-26 — rnd_vecsel channel extraction + hardware-status page

**§9 trigger question — does this entry alter, relax, or tighten any §1.5 Level 0 or
Level 1 parameter?** **No.**

- Affects-Level-0: no
- Affects-Level-1: no
- Affects-Success-Criteria: no
- Council-3-deliberation: not required (routine documentation; no architectural change)

## What

Extracted a sanitised in-house record from the internal `#rnd_vecsel` Mattermost channel
(2021–2026), mirrored read-only via the private `connect-to-mattermost` archive, and:

1. Added **`data/lab notes/2026-06-rnd-vecsel-channel-record.md`** — sanitised extraction
   (fleet status, 2026 operating points, open operational items), evidence class
   `[in-house, channel-derived, unverified]`, pending Steward cross-check.
2. Added **`docs/hardware-status.md`** — a public, sanitised hardware-status page (what
   has been built/done; current open items) distinct from the governance `status.md`.
3. Minor citations in `docs/tutorials/vecsel-systems.md`: filled the §4 / §5 **[open]**
   item on Heidi's (1141 nm) doubling route with the now-confirmed **extra-cavity LBO
   ring → ≈570 nm** (~110 mW, 2026), and listed the new lab note under "Lab notes".

## Steward-confirmed fact (2026-06-26)

**V#2 "Heidi" = the 1141 nm photoionisation unit, doubling 1141 → ≈570 nm** (first SHG
stage toward 285 nm), extra-cavity LBO ring. This resolves an apparent fleet-ID ambiguity
in an earlier draft of the extraction (which mis-read the LBO output as 559 nm from a
1118 unit). No conflict with the tutorial's #2 assignment.

## Sanitisation

Personal names → roles; vendor prices/quotes/PO numbers, e-mail/phone, internal
IPs/credentials, server paths, and chat permalinks omitted. Attachments remain
local-only in the private archive. The public pages assert only physics/results at the
existing tutorial's evidence level.

## Status

DRAFT — not promoted to Coastline; figures marked `[in-house, unverified]` pending
cross-check against the primary lab logbook.

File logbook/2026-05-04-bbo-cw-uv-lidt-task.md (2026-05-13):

# BBO CW-UV LIDT and operational-lifetime literature task — 2026-05-04

## Header (Charter §9 trigger question)

- **Affects Level 0 parameter?** no — task is a literature-search scope, not a Level 0 change
- **Affects Level 1 parameter?** *potentially*, depending on outcome — a tight CW-UV LIDT bound at 280 nm could constrain the §1.5 Level 1 *thermal-load envelope* and *intracavity intensity at the UV crystal* parameters. If the literature search converges on a tight bound, the constraint enters Level 1 via the [§1.5 asymmetric erosion-protection rule](../CHARTER.md) (tightening permitted with documented rationale). Logged here so future readers can trace the chain when it happens.
- **Affects success criterion?** no — this task does not change §6 success criteria; it informs the design-space envelope they get evaluated against.

## Stance attribution

- Task draft: assistant under steward direction
- Steward sign-off: pending

## Context

This is the **residual task E** carried over from [`logbook/2026-05-04-bbo-alternative-references.md`](2026-05-04-bbo-alternative-references.md), now opened as its own logbook entry because:

1. The CW-UV LIDT literature is *structurally different* from the Sellmeier / `d_eff` literature handled by tasks A and B. Tasks A and B had a single canonical primary source each (Eimerl 1987, Eckardt 1990, Tamošauskas 2018) — the dispersion equations and the nonlinear-coefficient measurements are mature, well-cited corners of the field with a small number of definitive papers. CW-UV-degradation work is not like that: there is no "canonical" CW-UV LIDT paper for BBO at 280 nm, and most published damage thresholds are *pulsed* (ns or shorter). CW operational lifetime data tends to be embedded in *application papers* (e.g. trapped-ion experiment papers reporting "we replace the BBO every X months") rather than dedicated damage studies.
2. The figure of merit is **operational lifetime under realistic CW intensities and gas environments**, not a single CW-LIDT W/cm² threshold. The intrinsic single-shot damage threshold is well above any CW operating condition; what matters is *time to degradation* — surface, bulk, or coating-mediated — under continuous exposure at ~10–100 W/cm² intracavity intensities, which is what the §5 Phase 1 evidence-table cell captures and what the Friedenauer-baseline architecture actually runs at.
3. This task touches **three dossier entries**, not one. Most of the LIDT discussion belongs in `KD-UV280-005` Section C (the headline number for the §5 Phase 1 evidence-table). The gas-environment / hygroscopic dimension belongs in `KD-UV280-009`. The mechanism (UV-induced colour-centre formation, photo-darkening, surface degradation) belongs in `KD-UV280-011`. Splitting the task to a separate logbook entry lets the three dossier entries pull from one shared candidate-reference list.

## Scope clarification

The task seeks evidence on three operationally distinct quantities, not one:

### Q1 — Intrinsic CW damage threshold at 280 nm

The CW intensity at which *prompt* surface or bulk damage occurs in fresh, high-quality BBO at 280 nm. Likely well above any operating condition in a Friedenauer-class system (where the intracavity intensity is ~10–100 W/cm²); a literature value here primarily sets the headroom for higher-intensity architectures rather than constraining the current baseline.

### Q2 — Operational lifetime under CW UV

Time-to-degradation curves under continuous 280 nm exposure at fixed intensity, fluence, and gas environment. This is what *actually* governs the Friedenauer-class baseline's maintenance schedule (Friedenauer 2006 itself does not report a lifetime; the original MPQ Garching apparatus and its Freiburg descendants would have institutional records here, see Q4). The relevant axes are:

- Intensity (W/cm² intracavity)
- Cumulative fluence (J/cm²·hours)
- Gas environment (ambient air, dry N₂, dry O₂, dry-gas-purged sealed enclosure)
- Surface preparation (Brewster-cut polish quality, AR-coating presence and condition)
- Crystal vendor / growth lot

### Q3 — Mechanism

What *kind* of degradation dominates under CW UV — photo-induced colour-centre absorption (bulk), surface photodissociation in the presence of trace water, coating delamination, or polishing-defect-mediated catastrophic damage. Mechanism affects which mitigations (dry-gas housing, periodic re-polishing, vendor switching, coating swap) are effective and which are not. Belongs in `KD-UV280-011 Section C` (mechanism) and feeds back into `KD-UV280-005 Section C` (operational threshold) and `KD-UV280-009 Section C` (gas environment).

### Q4 — Institutional [I] context

The Friedenauer 2006 baseline apparatus was originally built at MPI für Quantenoptik (Garching, Hänsch / Schätz collaboration) and the steward's group at AG Schätz / Albert-Ludwigs-Universität Freiburg is its descendant. Operational-lifetime records from the original MPQ apparatus and from the present-day Freiburg setup are likely the *highest-quality* CW-UV-LIDT-at-280-nm evidence available, but they are institutional rather than peer-reviewed. The dossier admits these as `[I]` tier per the [Section C source-tier rule](../docs/KD-2026-XXX-uv-280nm.md), provided the entry is classified Underdetermined unless external corroboration is found. This task should explicitly seek out the institutional record alongside the published literature, and document both clearly.

## Candidate references

Bibliographic details are this assistant's best recollection from training corpus and may have errors; the steward should verify before requesting PDFs. Ranked by expected payoff for `KD-UV280-005` Section C.

### A. CW-UV degradation studies on BBO in the 200–300 nm range

The closest literature to a "canonical" CW-UV-LIDT BBO paper is around the 200–300 nm Nd:YAG harmonic range. Candidates the steward may want to scout:

1. **Roth, Tzankov, Petrov 2005-era studies on BBO at 213 nm.** *Optical Materials* or *Applied Physics B* range. Frame: 5th-harmonic-of-Nd:YAG CW operation with explicit lifetime characterisation.
2. **Yoshida, Fujita, Nakatsuka et al. (mid-2000s) on UV-induced absorption in BBO.** *Japanese Journal of Applied Physics* or *Optics Communications* range. Frame: photo-induced absorption mechanism studies, not lifetime per se but informative for Q3.
3. **Cabrera-Granado, Díaz-Caballero et al. work on CW UV degradation in nonlinear crystals at 213 / 266 nm.** Frame: harmonic-of-1064 CW operations.
4. **Nikogosyan 2005 compendium chapter on BBO** — *Nonlinear Optical Crystals: A Complete Survey*, Springer. Already on the [task A/B candidate list](2026-05-04-bbo-alternative-references.md) as `[S:Nikogosyan2005]`. Will likely have a damage-and-degradation summary section that points to primary sources for both pulsed and CW regimes.

### B. Operational-lifetime evidence from trapped-ion / quantum-optics groups using BBO at 280 nm

The class of groups operating Mg⁺ / Be⁺ trapped-ion systems with BBO-at-280-nm cooling lasers is small enough that scouring their published apparatus papers should yield maintenance-schedule information. Candidate group + paper threads:

1. **Friedenauer 2006 itself (MPQ Garching → Freiburg lineage).** Already in the dossier as `[P:Friedenauer2006]`. Reports stability observations (fluctuations within 2%, microsecond drops < 4%, and 10% temperature-driven oscillations over 2 K environmental change) but does *not* state a crystal-replacement schedule or long-term lifetime figure. The institutional [I] record for this apparatus and its successors should be pursued separately (see Q4 above).
2. **NIST / Boulder ion-trap group** (Wineland and successors). Published cooling-laser apparatus details for ²⁵Mg⁺ over multiple decades; some papers may report BBO replacement intervals.
3. **University of Innsbruck (Blatt, Roos)** Be⁺ / Ca⁺ work — adjacent UV crystal use, may have transferable observations.
4. **University of Sussex / Oxford / NPL** quantum-computing groups using ²⁵Mg⁺ or ²⁴Mg⁺ — the more recent (2015+) experimental papers may have explicit BBO-related supplementary material.
5. **AG Schätz Freiburg internal records** — `[I]` tier; the steward's institutional access route. Highest-priority pursuit because directly relevant to the Friedenauer-baseline maintenance history.

### C. Coating-side degradation literature (feeds KD-UV280-008 / -012, not -005)

The dossier already has `KD-UV280-008` (UV mirror coatings — HR, OC, AR specifications and degradation) and `KD-UV280-012` (UV mirror coating degradation under CW exposure) as scaffolded entries. CW-UV coating-degradation literature is typically more developed than crystal-bulk CW-UV degradation; standard candidates are:

1. **Stolz, Genin et al. (LLNL / Spica) UV-coating CW-damage studies** — laser-damage-symposium proceedings, mostly pulsed but sometimes extended to high-repetition-rate / quasi-CW.
2. **Gallais, Commandré et al. UV coating studies.**
3. **Vendor application notes from Layertec, FEEFO, Lambda Research Optics, EKSMA Optics** — `[S]` tier; useful as supplementary but not as Section C primary anchors.

This task should *not* attempt to populate `KD-UV280-008` / `-012`; it should only flag references that crossover into the BBO-at-280-nm context. Coating-only literature search is its own future task.

### D. CLBO comparison literature (feeds KD-UV280-006 / -009)

CW-UV-degradation studies on CLBO at 266 nm and 213 nm are *more developed* than on BBO at 280 nm because CLBO is the workhorse for the Nd:YAG 5th harmonic in the deep-UV. The CLBO literature is the closest analogue and provides:

1. **A point of comparison** for the BBO operational-lifetime numbers when they emerge.
2. **A potential alternative crystal** — `KD-UV280-006` (CLBO at 280 nm) is currently SCAFFOLD; if the BBO CW-UV-LIDT picture turns out unfavourable, CLBO becomes more attractive.
3. **Mechanistic insight transferable to BBO** — both are borate crystals; some surface-degradation mechanisms (water-mediated, OH-incorporation) are shared.

Candidates: Sasaki et al. (Osaka group) on CLBO; Yoshimura, Takei et al. on CLBO durability under CW UV. This task should capture the CLBO citations alongside the BBO ones since they share the bibliographic search path.

### E. Single-source CW-UV-LIDT compendium / vendor sheets

Candidates: SNLO documentation; vendor catalogues from Crystals of Siberia, CASTECH, EKSMA Optics, FEEFO. `[S]` tier — admissible as secondary but not as Section C anchors. Useful primarily for *bracketing* the bulk-LIDT number.

## First scout pass — 2026-05-05

Source basis: public publisher / index metadata and abstracts only; no publisher PDFs downloaded or committed. This is a triage pass for choosing which papers deserve steward PDF retrieval and structured extraction.

### Search boundary

- Searched first for direct `BBO` + `280 nm` + `continuous-wave` / `lifetime` / `degradation` / `Mg+` combinations.
- Then expanded to adjacent-wavelength `BBO` evidence at 266 nm and 213 nm, plus application papers from trapped-ion Mg systems.
- No direct peer-reviewed BBO-at-280-nm CW operational-lifetime paper surfaced in this shallow web scout. This is **not** an exhaustion claim; library database / citation-chaining and the institutional Q4 route remain open.

### Verified candidate triage

| Candidate | Source metadata verified | Regime | Task-E mapping | First-pass triage |
|---|---|---|---|---|
| `Kondo1998` | K. Kondo, M. Oka, H. Wada, T. Fukui, N. Umezu, K. Tatsuki, S. Kubota, "Demonstration of long-term reliability of a 266-nm, continuous-wave, frequency-quadrupled solid-state laser using β-BaB₂O₄," *Optics Letters* **23**, 195-197 (1998), DOI `10.1364/OL.23.000195`. Optica abstract reports >1000 h operation, 100 mW cw 266 nm output, 500 mW incident 532 nm on the external BBO doubler, and degradation rate proportional to UV optical field. | CW, 266 nm, BBO, operational reliability | Q2 adjacent-wavelength anchor; possible Q1/Q2 bridge for `KD-UV280-005` | **Highest payoff published source found so far.** Not 280 nm, but closest peer-reviewed CW-BBO lifetime-style anchor. Needs PDF extraction for cavity waist / UV power density / sample / surface / gas-environment details before it can support the dossier. |
| `Kubota1998` | S. Kubota et al., "Efficient 213 nm and 266 nm generations in Czochralski-grown beta-barium borates," OSA Trends in Optics and Photonics **17**, paper FC4 (1998), DOI `10.1364/DLAI.1998.FC4`. Optica abstract reports >1000 h reliability test for three Cz-grown BBO samples in 100 mW 266 nm generation; cavity-loss increase `5e-5 %/hour` at generated UV power density 260 W/cm²; pulsed 266 nm comparison at 31 MW/cm². | CW and pulsed, 266 nm, BBO, conference proceeding | Q2 adjacent-wavelength anchor; sample-to-sample reliability | **High payoff supplement to Kondo1998.** Likely same Sony / Kubota programme; may contain the missing power-density and sample details. Proceedings status should be recorded explicitly if used as `[P]` or as lower-tier evidence. |
| `Takachiho2014` | K. Takachiho, M. Yoshimura, Y. Takahashi, M. Imade, T. Sasaki, Y. Mori, "Ultraviolet laser-induced degradation of CsLiB₆O₁₀ and β-BaB₂O₄," *Optical Materials Express* **4**, 559-567 (2014), DOI `10.1364/OME.4.000559`. Abstract reports high-repetition-rate pulsed 266 nm tests; BBO shows lower UV transmittance around 10 MW/cm² and absorption increasing with time due to absorption-center formation; CLBO degradation mechanism differs. | High-repetition-rate pulsed, 266 nm, BBO/CLBO, mechanism | Q3 mechanism for `KD-UV280-011`; adjacent-wavelength caveat for `KD-UV280-005` | **High payoff for mechanism, not for CW lifetime.** Do not use as the headline CW LIDT constraint; use to separate absorption-center / colour-centre mechanism from surface or coating failure. |
| `Sudmeyer2008` | T. Südmeyer, Y. Imai, H. Masuda, N. Eguchi, M. Saito, S. Kubota, "Efficient 2nd and 4th harmonic generation of a single-frequency, continuous-wave fiber amplifier," *Optics Express* **16**, 1546-1551 (2008), DOI `10.1364/OE.16.001546`. Optica abstract reports 12.2 W cw 266 nm output from a 6-mm critically phase-matched, AR-coated Cz-grown BBO operated at 40 °C. | CW, 266 nm, BBO, high-power demonstration | Q1/Q2 headroom and power-scaling context | **Medium-high payoff.** Strong high-power BBO-operability evidence, but likely less directly a lifetime paper; extract only after Kondo/Kubota unless full text reveals long-term degradation curves. |
| `Kjaergaard2000` | N. Kjærgaard et al. application paper PDF metadata: *Applied Physics B* **71**, 207-210 (2000), DOI `10.1007/s003400000296`. The paper states a single-mode cw dye laser is frequency doubled in a 5-mm BBO crystal in an external bow-tie cavity, designed around 560 nm but used at Mg/Ca photoionization wavelengths; the Mg cooling transition at 280 nm is driven by a nearly identical laser system. | Trapped-ion application, CW near 280/285 nm, BBO | Q2 operational application; no lifetime number seen in first pass | **Medium payoff.** Useful proof that BBO-at-280-class systems were normal in Mg ion labs before Friedenauer, but not yet a lifetime source. Full paper already accessible; likely extraction would be lightweight. |
| `Hume2010Thesis` | D. B. Hume thesis, *Two-Species Ion Arrays for Quantum Logic Spectroscopy* (NIST, 2010). Public NIST PDF states Mg-Doppler visible light is frequency doubled to 280 nm with a BBO doubling cavity; the Mg-Raman source is doubled first in LBO and then in BBO to 280 nm. | Trapped-ion institutional thesis, CW 280 nm, BBO | Q2 operational corroboration; non-`[P]` | **Medium-low payoff unless it contains maintenance notes elsewhere.** Useful as an application-source breadcrumb toward NIST operational records, not a Section C primary anchor. |
| `Burd2016` | S. C. Burd et al., "VECSEL systems for the generation and manipulation of trapped magnesium ions," *Optica* **3**, 1294-1300 (2016). Optica abstract verifies externally frequency-quadrupled VECSEL operation for 279.6 / 280.4 nm Mg⁺ cooling/repumping and state manipulation. | Trapped-ion application, 280 nm Mg⁺, crystal details require full-text check | Q2 application corroboration | **Medium-low payoff for Task E.** Important modern Mg⁺ source paper, but the abstract does not expose BBO lifetime or even the conversion-crystal details; retrieve only if citation-chaining suggests supplemental operational data. |
| `Sakuma2004_CLBO213` | J. Sakuma, Y. Asakawa, T. Imahoko, M. Obara, "Generation of all-solid-state, high-power continuous-wave 213-nm light based on sum-frequency mixing in CsLiB₆O₁₀," *Optics Letters* **29**, 1096-1098 (2004), DOI `10.1364/OL.29.001096`. Abstract reports >100 mW cw 213 nm using two Brewster-cut CLBO crystals. | CW, 213 nm, CLBO | D / `KD-UV280-006` comparison; gas-environment analog for `KD-UV280-009` | **Comparison source only.** Keep on the search path because CLBO literature may explain dry-gas / heated-housing protocols, but do not use to close BBO LIDT. |
| `Nishioka2005_CLBOWater` | M. Nishioka, A. Kanoh, M. Yoshimura et al., "Improvement in UV Optical Properties of CsLiB₆O₁₀ by Reducing Water Molecules in the Crystal," *Japanese Journal of Applied Physics* **44**, L699-L700 (2005), DOI `10.1143/JJAP.44.L699`. CiNii / ResearchGate metadata reports long-term heat treatment removes water molecules, improves 266 nm transmittance, and enables three-times higher 266 nm output without bulk damage. | CLBO, water / heat-treatment, 266 nm | D / `KD-UV280-009` environmental-control analogue | **Good CLBO environment anchor.** Mechanistically adjacent to BBO surface/gas questions, but should stay in the CLBO/environment branch unless a BBO-specific water mechanism is found. |

## Second scout pass — 2026-05-05 (assistant review)

Source basis: public publisher / index metadata, abstracts, and citation-context snippets only; no publisher PDFs downloaded or committed. This pass targeted BBO-specific LIDT reviews, high-repetition-rate UV degradation studies, and trapped-ion application papers the first pass missed.

### Search boundary

- Searched for BBO-specific LIDT review / compendium papers, two-photon absorption and color-centre formation at 262–266 nm, high-repetition-rate picosecond UV sources (quasi-CW thermal-loading regime), and additional Mg⁺ trapped-ion papers citing BBO at 280 nm.
- No direct peer-reviewed BBO-at-280-nm CW operational-lifetime paper surfaced in this pass either. The negative result from the first pass stands.

### Additional verified candidate triage

| Candidate | Source metadata verified | Regime | Task-E mapping | First-pass triage |
|---|---|---|---|---|
| `Turcicova2022` | H. Turcicova, O. Novak, J. Muzik, D. Stepankova, M. Smrz, T. Mocek, "Laser induced damage threshold (LIDT) of β-barium borate (BBO) and cesium lithium borate (CLBO) – Overview," *Optics & Laser Technology* **149**, 107876 (2022), DOI `10.1016/j.optlastec.2022.107876`. Review paper collecting published LIDT data for BBO and CLBO across pulse durations; discusses intrinsic / extrinsic factors and authors' own FiHG experience. | Review; mostly pulsed LIDT, but frames CW-relevant extrinsic factors (coatings, impurities, thermal load) | Q1 LIDT bracketing; Q3 extrinsic-factor context; bibliographic hub for primary sources | **High payoff as a bibliographic hub.** Explicitly collects prior LIDT measurements; likely points to primary sources the scout passes missed. Should be extracted early to harvest its reference list for CW-adjacent studies. Not a CW lifetime anchor itself. |
| `Kumar2015` | S. Chaitanya Kumar, J. Canals Casals, J. Wei, M. Ebrahim-Zadeh, "High-power, high-repetition-rate performance characteristics of β-BaB₂O₄ for single-pass picosecond ultraviolet generation at 266 nm," *Optics Express* **23**, 28091-28103 (2015), DOI `10.1364/OE.23.028091`. Reports dynamic color-center formation from two-photon absorption in BBO at 266 nm; TPA coefficient ~3.5× lower at 200 °C than at 22 °C; long-term power stability >8 h at 2.9 W average power, 80 MHz. | High-repetition-rate picosecond (quasi-CW thermal loading), 266 nm, BBO, color-center mechanism | Q3 mechanism for `KD-UV280-011`; temperature-mitigation evidence for `KD-UV280-009`; adjacent-wavelength headroom for `KD-UV280-005` | **High payoff for mechanism and thermal mitigation.** The temperature-dependent TPA data is directly transferable to the Friedenauer-class thermal-load envelope. The 80 MHz, multi-watt average-power regime is thermally closer to CW than single-shot pulsed studies. |
| `Takahashi2010` | M. Takahashi, A. Osada, A. Dergachev, P. F. Moulton, M. Cadatal-Raduban, T. Shimizu, N. Sarukura, "Effects of Pulse Rate and Temperature on Nonlinear Absorption of Pulsed 262-nm Laser Light in β-BaB₂O₄," *Japanese Journal of Applied Physics* **49**, 080211 (2010), DOI `10.1143/JJAP.49.080211`. Investigates nonlinear absorption in BBO at 262 nm as a function of pulse rate and crystal temperature. | Pulsed, 262 nm, BBO, nonlinear absorption / color-center precursor | Q3 mechanism; adjacent-wavelength (262 nm ≈ 280 nm) | **Medium-high payoff for mechanism.** 262 nm is closer to 280 nm than 266 nm; pulse-rate dependence may reveal quasi-CW behavior. Extract to correlate with Kumar2015 temperature data. |
| `Isaenko2001` | L. I. Isaenko, A. Dergachev, D. G. Machonkin, D. N. Nikogosyan, "Anisotropy of two-photon absorption in BBO at 264 nm," *Optics Communications* **198**, 433-438 (2001). | Pulsed, 264 nm, BBO, two-photon absorption anisotropy | Q3 mechanism | **Medium payoff for mechanism.** Early TPA characterization; useful for validating later Kumar2015 / Takahashi2010 numbers. |
| `Hemmerling2011` | B. Hemmerling, F. Gebert, Y. Wan, T. K. Cubel Liebisch, N. Akerman, M. Carreras, D. Cianchetti, S. Kraft, J. P. Paetzold, S. R. de Echaniz, U. Warring, T. W. Koerber, H. Haeffner, F. Schmidt-Kaler, "A single laser system for ground-state cooling of ²⁵Mg⁺," *Applied Physics B* **104**, 583-590 (2011), DOI `10.1007/s00340-011-4472-9`. Reports a 280 nm cooling laser for ²⁵Mg⁺ using BBO second-harmonic generation. | Trapped-ion application, CW 280 nm, BBO | Q2/Q4 operational corroboration | **Medium payoff.** Directly relevant to the Friedenauer-class architecture; may contain operational notes or reference institutional maintenance records. |
| `Nagashima2009` | T. Nagashima, N. Seko, K. Tatsuki, H. Tonooka, J. Murata, Y. Wada, "Thousand hours operations of CW DUV laser light…" (full title requires verification), *Applied Optics* or *Applied Physics B* (2009). Cited in recent 213-nm generation papers as the CW DUV long-term operation reference. | CW, DUV (likely 266 nm or 213 nm), operational lifetime | Q2 adjacent-wavelength anchor | **Medium-high payoff, pending title verification.** The "thousand hours" framing matches the Q2 operational-lifetime need. Steward should verify exact bibliographic details and retrieve. |
| `Deyra2015` | L. Deyra, A. Maillard, R. Maillard, D. Sangla, F. Salin, F. Balembois, A. E. Kokh, P. Georges, "Impact of BaB₂O₄ growth method on frequency conversion to the deep ultra-violet," *Solid State Sciences* (2015), DOI `10.1016/j.solidstatesciences.2015.10.019`. Compares flux-grown (TSSG) and Czochralski-grown BBO for deep-UV FHG; CZ-grown yields higher conversion efficiency under high average power. | Growth-method comparison, deep-UV, high average power | Q3 extrinsic factor (crystal quality); `KD-UV280-006` alternative-crystal context | **Medium payoff.** Supports the Kondo / Kubota Cz-grown BBO finding; may explain sample-to-sample lifetime variation. |
| `Bhar2004` | G. C. Bhar, A. K. Chaudhary, P. Kumbhakar, A. M. Rudra, S. C. Sabarwal, "A comparative study of laser-induced surface damage thresholds in BBO crystals and effect of impurities," *Optical Materials* **27**, 119-123 (2004), DOI `10.1016/j.optmat.2004.02.027`. Single-shot and multiple-shot surface damage thresholds at 1064 and 532 nm; SEM-EDXA impurity correlation. | Pulsed, 1064/532 nm, surface damage, impurities | Q1 distant bracket; Q3 extrinsic (impurity) factor | **Low-medium payoff for Task E.** Wavelength is far from 280 nm, but the impurity-damage correlation is transferable to UV surface degradation. Retrieve only if Turcicova2022 points to it as significant. |

### Updated priority after second scout pass

The priority list from the first scout pass is superseded as follows:

1. Retrieve / extract `Kondo1998` first, with `Kubota1998` as the companion.
2. Retrieve / extract `Turcicova2022` in parallel with step 1. Its reference list is likely to surface additional primary sources (including possibly CW-specific studies) that the scout passes missed.
3. Extract `Kumar2015` and `Takahashi2010` for mechanism (`KD-UV280-011`) and temperature-mitigation evidence (`KD-UV280-009`) once the CW anchor is secured.
4. Verify and retrieve `Nagashima2009` if the full title confirms CW DUV BBO operation; it may provide the missing >1000 h operational narrative.
5. Extract `Hemmerling2011` as a trapped-ion breadcrumb toward Q4 institutional records, and for any operational notes on the 280 nm BBO system.
6. Keep `Bhar2004`, `Isaenko2001`, and `Deyra2015` as lower-priority mechanistic / extrinsic context; extract only if steps 1–5 reveal gaps they can fill.
7. Start the Q4 institutional query in parallel; the expanded published literature still does not replace the value of MPQ Garching / AG Schätz Freiburg operating records at exactly 280 nm.

## Third scout pass — 2026-05-13 (filing of newly-arrived publisher PDFs)

Source basis: publisher / preprint PDFs newly arrived under `downloads/literature/task-e/` and inspected on 2026-05-13 (first-page and abstract / §1-2 read; no full extraction). The downloads batch confirms a number of previously-scaffolded candidates (Kondo1998, Kubota1998, Hemmerling2011, Kumar2015, Turcicova2022, Eckardt1990, Tamosauskas2018, Eimerl1987, Friedenauer2006, Hume2010, Burd2016, Kjaergaard2000, Brown2019) and **adds three new entries** plus one **scaffold authorship correction**.

### Bibliographic confirmations and additions

| Citation key | Filename in downloads batch | Folder status before 2026-05-13 | Folder status after 2026-05-13 |
|---|---|---|---|
| `Kondo1998` | `Kondo1998_OpticsLetters_user.pdf` (+ `_official_probe.html`) | DRAFT | unchanged |
| `Kubota1998` | `Kubota1998_OSAProceedings_user_scan.pdf` (+ `_official_probe.html`) | DRAFT | unchanged |
| `Hemmerling2011` | `Hemmerling2011_arxiv_open.pdf` | DRAFT | unchanged |
| `Kumar2015` | `Kumar2015_UPCommons_open.pdf` (+ Optica probe HTML) | DRAFT | unchanged |
| `Turcicova2022` | `Turcicova2022_Elsevier_user.pdf` | DRAFT | unchanged |
| `Eckardt1990` | `Eckardt1990_IEEE_user.pdf` | DRAFT | unchanged |
| `Tamosauskas2018` | `Tamosauskas2018_OME_user.pdf` | DRAFT | unchanged |
| `Eimerl1987` | `Eimerl1987_AIP_user.pdf` | DRAFT | unchanged |
| `Friedenauer2006` | `Friedenauer2006_Springer_user.pdf` | DRAFT (existing) | unchanged |
| `Hume2010` | `Hume2010_NIST_open.pdf` | existing scaffold | unchanged |
| `Burd2016` | `Burd2016_NIST_open.pdf` | existing scaffold | unchanged |
| `Kjaergaard2000` | `Kjaergaard2000_Aarhus_open.pdf` | existing scaffold | unchanged |
| `Brown2019` | `Brown2019_SciRep_open.pdf` | DRAFT (existing) | unchanged |
| **`Burkley2021`** | `vonMilczewski2021_arxiv_open.pdf` (misnomer; see correction below) | SCAFFOLD under wrong internal author | SCAFFOLD with corrected citation_key / citation strings |
| **`Hannig2018`** *(new)* | `013106_1_online.pdf` | n/a | SCAFFOLD created |
| **`Shaw2021`** *(new)* | `oe-29-23-37140.pdf` | n/a | SCAFFOLD created |
| **`Kraus2022`** *(new)* | `oe-30-25-44992.pdf` | n/a | SCAFFOLD created |

Two of the downloads batch are probe-only HTML captures with no associated PDF (`Kumar2015_Optica_captcha_probe.html`, `Takachiho2014_Optica_captcha_probe.html`) and one is a metadata-probe page for Kubota1998 / Kondo1998 (the actual PDFs are filed alongside). The Takachiho 2014 paper remains a published `[P]`-tier candidate per the second scout pass priority list but no PDF was retrieved in this batch.

### Scaffold authorship correction: `vonMilczewski2021` → `Burkley2021`

The 2026-05-06 scaffold under [`data/literature/Burkley2021/`](../data/literature/Burkley2021/) attributed the arXiv:`2105.14977` paper to a first author "von Milczewski" based on a public-metadata guess made before the PDF was in hand. Direct read of the PDF on 2026-05-13 confirms the correct first author is **Z. (Zakary) Burkley** (ETH Zürich), with co-authors L. de Sousa Borges, B. Ohayon, A. Golovozin (Lebedev), J. Zhang, and P. Crivelli. There is no author named "von Milczewski" on the paper. The folder name `Burkley2021/` was correct from creation; the internal `citation_key`, `citation`, and notes-header strings were the locus of the error and have been corrected in this pass. The download filename `vonMilczewski2021_arxiv_open.pdf` is retained in the gitignored `downloads/` tree as a historical artefact and is **not** renamed (renaming would break the chain-of-provenance trail back to the 2026-05-06 scout pass commit). The corresponding `cross_check_notes` entry `scout_pass_authorship_correction` is now logged in [`data/literature/Burkley2021/extracted.yaml`](../data/literature/Burkley2021/extracted.yaml), parallel to the matching note in [`data/literature/Hemmerling2011/extracted.yaml`](../data/literature/Hemmerling2011/extracted.yaml).

### Newly-added candidate triage

| Candidate | Source verified | Regime | Task-E mapping | Triage |
|---|---|---|---|---|
| `Hannig2018` | S. Hannig, J. Mielke, J. A. Fenske, M. Misera, N. Beev, C. Ospelkaus, P. O. Schmidt, "A highly stable monolithic enhancement cavity for second harmonic generation in the ultraviolet," *Review of Scientific Instruments* **89**, 013106 (2018), DOI `10.1063/1.5005515`. Brewster-cut BBO bow-tie cavity for 313 nm; **130 h uninterrupted operation without decay in output power**. Vibration robustness: <10 % in-lock variation at 1 g; 30 min at 3 g_rms. Open-source STEMlab 125-14 digital PI lock. Published Creative Commons CC-BY 4.0. | CW, 313 nm, Brewster-cut BBO, monolithic bow-tie | Q2 upper-wavelength operational-lifetime anchor for BBO cavity CW operation; combined with Kondo1998 / Kubota1998 at 266 nm, brackets the 280 nm operating point from above and below in wavelength | **High payoff.** One of the cleanest published examples of "no decay over multi-day BBO-cavity CW operation in the UV". PTB-Schmidt-group lineage, same as Hemmerling2011 / Kraus2022. Adjacent-wavelength caveat applies (313 nm sits deeper into the BBO transparency window than 280 nm). Next pass: full extraction of cavity geometry, BBO dimensions, intracavity power, gas environment. |
| `Shaw2021` | J. C. Shaw, S. Hannig, D. J. McCarron, "Stable 2 W continuous-wave 261.5 nm laser for cooling and trapping aluminum monochloride," *Optics Express* **29**, 37140-37155 (2021), DOI `10.1364/OE.441741`. LBO + CLBO cascaded bow-tie cavities (1046 nm ECDL + IPG fibre amp → 523 nm → 261.5 nm); **2.75 W peak / 2 W steady-state CW at 261.5 nm over 13 h**; "largely unexplored high-intensity regime in CLBO for continuous-wave DUV light" (abstract verbatim). Monolithic aluminium-housing bow-tie from Agile Optic GmbH (Hannig). Optica Open Access. | CW, 261.5 nm, CLBO + LBO cascade, high-intensity DUV | D (CLBO comparison literature) bracket; Q2 short-duration high-power CW DUV anchor on CLBO | **High payoff for the CLBO arm.** The 261.5 nm operating point and 2 W CW power scaling exceed prior published CLBO CW DUV anchors; directly relevant to `KD-UV280-006`. Next pass: full extraction of LBO + CLBO crystal specs, intracavity intensities, gas environment, output-power time trace. |
| `Kraus2022` | B. Kraus, F. Dawel, S. Hannig, J. Kramer, C. Nauk, P. O. Schmidt, "Phase-stabilized UV light at 267 nm through twofold second harmonic generation," *Optics Express* **30**, 44992-45003 (2022), DOI `10.1364/OE.471450`. Twofold *single-pass* SHG: 1069.6 nm fibre laser → 10 mm PPLN waveguide (HC Photonics) → 534.8 nm → 50 mm DKDP non-critical Type-I at ~100 °C → **267.4 nm at >50 µW with fractional frequency instability <5×10⁻¹⁷ at 1 s** (electronics-limited 1×10⁻¹⁸ at 1 s). Optica Open Access. | CW, 267.4 nm, DKDP + PPLN waveguide, no cavities | Architectural-alternative datapoint for `KD-UV280-006` and the alternative-topology slate. Not a Task-E LIDT or lifetime anchor. | **Medium payoff for Task E specifically; high payoff for the alternative-crystal / alternative-topology dossier branch.** PTB-Schmidt-group lineage with Hannig as bridging author. DKDP at 267 nm is structurally distinct from both BBO and CLBO; the trade-off is no walk-off and no cavity required, at the cost of ~10⁻⁴× lower output power than Friedenauer-class systems. Next pass: full extraction of DKDP operating conditions, PPLN waveguide specs, phase-stability method. |

### Cross-paper observation: PTB-Schmidt-group hardware lineage

The three newly-filed papers (`Hannig2018`, `Shaw2021`, `Kraus2022`) plus the previously-filed `Hemmerling2011` together span four distinct UV-stage architectures all attached to the same institutional lineage:

| Paper | Year | Stage architecture | Crystal | Wavelength | Headline result |
|---|---|---|---|---|---|
| Hemmerling2011 | 2011 | bow-tie cavity | Brewster-cut BBO | 280 nm | 60 mW UV; CW UV-induced surface damage on fused silica at 32-64 W/cm² over hours |
| Hannig2018 | 2018 | monolithic bow-tie cavity | Brewster-cut BBO | 313 nm | 130 h uninterrupted operation; vibration-robust |
| Shaw2021 | 2021 | LBO + CLBO cascaded monolithic bow-tie cavities | CLBO | 261.5 nm | 2 W steady-state over 13 h; "largely unexplored high-intensity regime" |
| Kraus2022 | 2022 | PPLN waveguide + DKDP single-pass | DKDP (non-critical Type-I) | 267.4 nm | <5×10⁻¹⁷ phase stability at 1 s |

Co-authors S. Hannig (PTB / Agile Optic GmbH) and P. O. Schmidt (PTB) appear across multiple combinations. The institutional Q4 record from the Schmidt group (per the task-E acceptance criterion #3) likely covers all four of these architectures, not only the Friedenauer-style BBO route; this widens the scope of the institutional-`[I]`-tier extraction window when the steward chooses to pursue it.

### Updated priority after third scout pass

The previous priority list is augmented (not replaced) with the new candidates:

1. *(unchanged)* Retrieve / extract `Kondo1998` and `Kubota1998` (now in hand under `downloads/literature/task-e/`).
2. *(unchanged)* Extract `Turcicova2022` (in hand) for its bibliographic-hub reference list.
3. *(unchanged)* Extract `Kumar2015` and `Takahashi2010` for mechanism / temperature-mitigation evidence.
4. **Extract `Hannig2018`** in parallel with step 1 — direct CW-BBO operational-lifetime anchor at 313 nm; the 130 h figure is one of the cleanest available.
5. **Extract `Shaw2021`** as the CLBO arm anchor at 261.5 nm; feeds `KD-UV280-006` and the alternative-crystal branch.
6. **Extract `Burkley2021`** (now with corrected scaffold) for the coating-and-gas-environment branch (`KD-UV280-008` / `-009` / `-012`).
7. *(unchanged)* Extract `Hemmerling2011` — already DRAFT.
8. **Extract `Kraus2022`** as architectural-alternative datapoint for the alternative-topology slate; lower priority for Task E itself.
9. *(unchanged)* Verify and retrieve `Nagashima2009`.
10. *(unchanged)* Keep `Bhar2004`, `Isaenko2001`, `Deyra2015` as lower-priority mechanistic / extrinsic context.
11. *(unchanged)* Start the Q4 institutional query, now widened to cover the four PTB-Schmidt-group UV-stage architectures identified above.

## Acceptance criteria for closing this task

This logbook entry is closed when **all** of the following are true:

1. At least **one** peer-reviewed `[P]` source is cited in `KD-UV280-005 Section C` for either Q1 (CW intrinsic threshold at 280 nm) or Q2 (operational-lifetime curve under realistic conditions). If no peer-reviewed source exists for Q1/Q2 specifically at 280 nm, the entry uses adjacent-wavelength `[P]` sources (e.g. 213, 266 nm) with explicit extrapolation rationale.
2. If adjacent-wavelength evidence is used because no direct 280 nm peer-reviewed source is found, the dossier explicitly states the search boundary and the negative result (databases / query family / date), so the 266 nm or 213 nm extrapolation is visible rather than silently promoted to a 280 nm measurement.
3. The institutional `[I]` record from MPQ Garching / AG Schätz Freiburg is either (a) extracted into a dedicated `data/literature/AG-Schatz-internal/` folder following the conventions in `data/literature/<key>/notes.md`, or (b) explicitly deferred with a documented reason. If included, the dossier entry classification per the [Section C `[I]`-only rule](../docs/KD-2026-XXX-uv-280nm.md) is Underdetermined unless external corroboration is found.
4. `KD-UV280-005` Section C "TODO: cite peer-reviewed CW LIDT measurements at 280 nm" bullet is replaced with the populated constraint. The `KD-UV280-009` Section C entry on gas-environment dependence either gains a populated `[P:]` constraint or pings back to this logbook entry as the deferred task.
5. The §5 Phase 1 evidence-table BBO row's "CW LIDT @ 280 nm (W/cm²)" cell either tightens (if A/B/C above produce a value) or splits into "intrinsic / operational lifetime" with separate citations.
6. `KD-UV280-011` is upgraded from SCAFFOLD to POPULATING if mechanism-level literature (Q3) is captured.

## Steward decision queue

This logbook entry is a *task draft*, not a closed gate. The steward decides:

- (a) Which of A / B / C / D to pursue first. Recommendation: **A in parallel with B** (A gives the published CW-UV-LIDT anchor; B gives the operational-lifetime corroboration from quantum-optics application papers). C and D are lower priority and can be deferred.
- (b) Whether to attempt institutional access at AG Schätz Freiburg / MPQ Garching for the Q4 institutional `[I]` record, and on what timeline. If yes, whether the resulting record is committed to the repository (with the same publisher-copyright-style discipline applied to redacting any unpublished data not cleared for release) or kept local.
- (c) Whether to split the resulting work across `KD-UV280-005` (LIDT headline number), `KD-UV280-009` (gas environment), and `KD-UV280-011` (mechanism), or to keep it concentrated under `-005` with cross-references.

## Cross-references

- [`logbook/2026-05-04-bbo-alternative-references.md`](2026-05-04-bbo-alternative-references.md) — parent task list; this entry handles the residual task E that was carved out.
- [`docs/KD-2026-XXX-uv-280nm.md`](../docs/KD-2026-XXX-uv-280nm.md) — KD-UV280-005 Section C "TODO: cite peer-reviewed CW LIDT measurements at 280 nm" is the binding open item. KD-UV280-009 (hygroscopic / environmental) and KD-UV280-011 (UV-induced degradation) are co-targets.
- [`data/literature/Eimerl1987/extracted.yaml`](../data/literature/Eimerl1987/extracted.yaml) — already records that Eimerl 1987's 13.5 J/cm² damage threshold is *not* a CW-UV LIDT (parameter `BBO_damage_threshold_1064nm_1ns`). This task is the formal forward-pointer to closing that explicit caveat.
- [`data/literature/Friedenauer2006/extracted.yaml`](../data/literature/Friedenauer2006/extracted.yaml) — `open_extraction_items` includes "No direct CW LIDT value at 280 nm is reported"; this task is the dossier-side closure path for that item too.

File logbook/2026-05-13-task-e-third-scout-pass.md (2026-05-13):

# Task-E literature filing — third scout pass and scaffold authorship correction

**Steward:** Ulrich Warring
**Date:** 2026-05-13
**Status:** OBSERVATIONAL RECORD (Phase 1-equivalent literature population). Three new SCAFFOLD entries created in `data/literature/`; one previously-misattributed SCAFFOLD corrected; the [task-E logbook](2026-05-04-bbo-cw-uv-lidt-task.md) extended with a third scout pass that cross-walks the 2026-05-13 downloads batch to folder status. No architecture-family-specific code; no change to any binding parameter.

## Header (CHARTER §9 trigger questions)

- **Affects Level 0 parameter?** no — the §1.5 Level 0 row (³P₁/₂–³P₃/₂ detuning, two-photon Rabi rate, allowed scattering rate) and the G3-closure reference triple `{Δ_ref = 40 GHz, Ω_R/2π = 400 kHz, Γ_sc = 2.0 × 10⁴ s⁻¹}` are not touched by literature population.
- **Affects Level 1 parameter?** no — three new SCAFFOLD entries plus one authorship correction do not, in themselves, tighten or relax any Level 1 row. Downstream DRAFT promotion of `Hannig2018` (130 h CW operation at 313 nm) and `Burkley2021` (oxide vs fluoride coatings under high-power deep-UV CW) *may* tighten KD-UV280-005 / -008 / -012 Section C constraints when those extractions are run, but no such tightening is asserted here.
- **Affects success criterion?** no.

This entry therefore does not require Council-3 deliberation. It is a **literature-tracking-chain maintenance entry**: filing newly-arrived PDFs, fixing a 2026-05-06 scaffold-era authorship error, and weaving both into the task-E candidate list.

## Anti-seeding boundary

This entry is admissible under Phase 1 (`docs/principles.md` "Anti-seeding clause" — Phase 1 dossier population is unblocked; architecture-family-specific simulation in `/src/` is forbidden until G1 closes). The work introduces no new architecture preset, no new simulation code, and no new parameter constant. All four affected `data/literature/<key>/` folders carry `extraction_status: SCAFFOLD`; no numerical values from the article bodies have been promoted to `extracted.yaml` parameters in this pass.

---

## 1 · What was filed

Three publisher PDFs newly arrived in `downloads/literature/task-e/` on 2026-05-13 were inspected (first-page + abstract + §1-2 read) and given SCAFFOLD entries under `data/literature/`. None of the three were previously on the candidate list in either of the prior scout passes — they surfaced through the steward's institutional access route rather than through the assistant's web-scout queries.

| Citation key | Reference | Wavelength | Headline result |
|---|---|---|---|
| **`Hannig2018`** | S. Hannig, J. Mielke, J. A. Fenske, M. Misera, N. Beev, C. Ospelkaus, P. O. Schmidt, *Rev. Sci. Instrum.* **89**, 013106 (2018), DOI `10.1063/1.5005515` | 313 nm | Brewster-cut BBO bow-tie cavity; **130 h uninterrupted CW operation, no decay in output power**; vibration-robust (<10 % output variation at 1 g, 30 min at 3 g_rms); STEMlab 125-14 (Red Pitaya) digital PI lock |
| **`Shaw2021`** | J. C. Shaw, S. Hannig, D. J. McCarron, *Opt. Express* **29**, 37140-37155 (2021), DOI `10.1364/OE.441741` | 261.5 nm | LBO + CLBO cascaded monolithic bow-tie cavities (1046 nm ECDL + IPG fibre amp source); **2.75 W peak / 2 W steady-state CW at 261.5 nm over 13 h**; "largely unexplored high-intensity regime in CLBO for continuous-wave DUV" (abstract verbatim) |
| **`Kraus2022`** | B. Kraus, F. Dawel, S. Hannig, J. Kramer, C. Nauk, P. O. Schmidt, *Opt. Express* **30**, 44992-45003 (2022), DOI `10.1364/OE.471450` | 267.4 nm | Twofold *single-pass* SHG: 1069.6 nm fibre laser → 10 mm PPLN waveguide → 534.8 nm → 50 mm DKDP non-critical Type-I → 267.4 nm at >50 µW; fractional frequency instability **<5 × 10⁻¹⁷ at 1 s** (beat-note); 1 × 10⁻¹⁸ at 1 s electronics-limited |

All three are open-access at the publisher (Hannig 2018 under Creative Commons CC-BY 4.0 via AIP; Shaw 2021 and Kraus 2022 under the OSA / Optica Open Access Publishing Agreement). The publisher PDFs are therefore **admissible** for commit under the project's mixed-licence policy (cf. `LICENSES.md`), but the three SCAFFOLD entries defer that decision to the steward and currently keep the PDFs only in the gitignored `downloads/` tree.

## 2 · What was corrected

One previously-filed SCAFFOLD entry was corrected for authorship attribution.

**`data/literature/Burkley2021/`** was created on 2026-05-06 as a scaffold for arXiv:`2105.14977` *before* the PDF was in hand. The scaffold's first-author guess "von Milczewski" was committed into the YAML and notes files (`citation_key: "vonMilczewski2021"`, `citation: "J. S. B. von Milczewski et al. …"`) despite the folder itself being named `Burkley2021/` from creation. Direct read of the arXiv PDF on 2026-05-13 confirms the correct author list:

> Z. (Zakary) Burkley, L. de Sousa Borges, B. Ohayon, A. Golovozin, J. Zhang, P. Crivelli
> "Stable High Power deep-UV Enhancement Cavity in Ultra High Vacuum with Fluoride Coatings"
> arXiv:2105.14977v1 (31 May 2021)
> Affiliations: ETH Zürich (Burkley, de Sousa Borges, Ohayon, Zhang, Crivelli); Lebedev Physical Institute, Moscow (Golovozin)

There is no author named "von Milczewski" on the paper. The folder name `Burkley2021/` is correct; the `citation_key`, `citation`, `title`, and `source_document` strings inside `extracted.yaml` and the heading inside `notes.md` were rewritten in this pass. A `cross_check_notes` entry `scout_pass_authorship_correction` is now logged in [`data/literature/Burkley2021/extracted.yaml`](../data/literature/Burkley2021/extracted.yaml), parallel to the matching note already in [`data/literature/Hemmerling2011/extracted.yaml`](../data/literature/Hemmerling2011/extracted.yaml) (which records a different but procedurally identical scaffold-era misattribution).

**Filename retained.** The download filename `vonMilczewski2021_arxiv_open.pdf` is retained in the gitignored `downloads/literature/task-e/` tree as a historical artefact of the 2026-05-06 scout-pass commit. Renaming it would break the chain-of-provenance trail back to that commit (which is in `git log`) without any compensating benefit, since the downloads tree is not part of the published repository.

## 3 · How the entries weave into the task-E chain

A third scout pass section was appended to [`logbook/2026-05-04-bbo-cw-uv-lidt-task.md`](2026-05-04-bbo-cw-uv-lidt-task.md) immediately before the "Acceptance criteria" section. It contains:

1. **A 16-row table** cross-walking every download in `downloads/literature/task-e/` to its current folder status (DRAFT for the already-extracted ones, SCAFFOLD-with-corrected-attribution for Burkley2021, and SCAFFOLD-newly-created for Hannig2018 / Shaw2021 / Kraus2022).
2. **The Burkley2021 authorship correction**, with the rationale reproduced from §2 above and an explicit pointer to the parallel `scout_pass_authorship_correction` in Hemmerling2011.
3. **A three-row triage table** for the three new candidates, mapping each to one or more of the Task-E sub-questions (Q1 intrinsic threshold, Q2 operational lifetime, Q3 mechanism, Q4 institutional context) and branches (BBO-cavity, CLBO comparison, alternative-topology).
4. **A cross-paper observation** that the four PTB-Schmidt-group-related papers in the dossier (`Hemmerling2011`, `Hannig2018`, `Shaw2021`, `Kraus2022`) now span four distinct UV-stage architectures (Brewster-cut BBO bow-tie cavity at 280 nm; Brewster-cut BBO monolithic bow-tie at 313 nm; LBO + CLBO cascaded monolithic bow-tie at 261.5 nm; PPLN waveguide + DKDP single-pass at 267.4 nm), with Hannig (PTB / Agile Optic GmbH) as the bridging co-author. This widens the scope of the institutional-`[I]`-tier extraction window when the steward chooses to pursue task-E acceptance criterion #3 (the MPQ Garching / AG Schätz Freiburg / PTB Braunschweig institutional record).
5. **An updated priority list** that augments rather than replaces the second scout pass's ranking, inserting Hannig2018 in parallel with Kondo1998 / Kubota1998 / Turcicova2022 at the top tier, then Shaw2021, Burkley2021, Hemmerling2011, and Kraus2022 in descending order.

## 4 · What is *not* in this entry

- **No full extraction of any of the three new papers.** All three SCAFFOLDs enumerate their highest-priority numerical extraction targets but leave them open. Promoting `Hannig2018` to DRAFT (in particular the 130 h figure and the operating conditions under which it was observed) is the highest-payoff next pass.
- **No update to KD-UV280-005, -006, -008, -009, or -012 Section C.** The dossier consumes the extractions, not the scaffolds. Updates to Section C wait for DRAFT promotion of the relevant entries.
- **No assertion that the Burkley2021 authorship correction implies a systematic problem with the 2026-05-06 scout pass.** It is the second confirmed scaffold-era author misattribution (after Hemmerling2011's `scout_pass_authorship_correction`, which speculated U. Warring as a co-author when he is not). Two confirmed cases is enough to record the pattern; a third instance, if found, should trigger a re-audit of all 2026-05-06 SCAFFOLD-only entries against their PDFs. For now, the rule "verify authorship against the PDF before promoting SCAFFOLD → DRAFT" is sufficient and is already part of the de-facto extraction workflow.

## 5 · Charter compliance

**Anti-seeding boundary.** All four affected folders are at `extraction_status: SCAFFOLD`; no numerical value from any article body has been promoted in this pass. No simulation code is committed; no parameter constant is changed.

**Gate status.** G3 closed 2026-05-01; the reference triple is unaffected. G1 (14-GHz unlockable-domain attribution) and G2 (UV-induced degradation at 280 nm) remain open and are not advanced by this entry.

**Provenance tier.** All three new entries are filed as `source_tier: P` (peer-reviewed primary) consistent with the journal venues (Rev. Sci. Instrum., Optics Express ×2). The Burkley2021 correction is at `source_tier: P` (arXiv preprint; journal status to be confirmed in a later pass).

**Asymmetric erosion protection.** No tightening or relaxation of any Level 0 / Level 1 parameter is proposed. Nothing on this page weakens any committed CHARTER row.

## 6 · See also

- [`logbook/2026-05-04-bbo-cw-uv-lidt-task.md`](2026-05-04-bbo-cw-uv-lidt-task.md) — task-E task draft; the third scout pass section appended in this work is the chain-anchor for the entries filed today.
- [`logbook/2026-05-04-bbo-alternative-references.md`](2026-05-04-bbo-alternative-references.md) — parent task draft (tasks A-E) from which task-E was carved out.
- [`data/literature/Hannig2018/`](../data/literature/Hannig2018/), [`data/literature/Shaw2021/`](../data/literature/Shaw2021/), [`data/literature/Kraus2022/`](../data/literature/Kraus2022/) — the three new SCAFFOLD entries.
- [`data/literature/Burkley2021/`](../data/literature/Burkley2021/) — the corrected scaffold (folder name unchanged from 2026-05-06; internal citation strings updated).
- [`data/literature/Hemmerling2011/extracted.yaml`](../data/literature/Hemmerling2011/extracted.yaml) — `cross_check_notes.scout_pass_authorship_correction`, the procedurally identical correction filed in a previous pass.
- [`docs/KD-2026-XXX-uv-280nm.md`](../docs/KD-2026-XXX-uv-280nm.md) — the dossier entries (KD-UV280-005, -006, -008, -009, -012) that will consume the new extractions when they are promoted SCAFFOLD → DRAFT.

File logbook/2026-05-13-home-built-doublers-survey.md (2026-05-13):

# Home-built BBO doublers — photographic survey and fold-angle extraction

**Steward:** Ulrich Warring
**Date:** 2026-05-13
**Status:** OBSERVATIONAL RECORD (Phase 1-equivalent literature / lab artefact). Three top-view photographs archived; per-doubler geometric extraction and photogrammetric fold-angle estimate committed to [`docs/components/home-built-doublers.md`](../docs/components/home-built-doublers.md). No architecture-family-specific code; no change to any binding parameter.

## Header (CHARTER §9 trigger questions)

- **Affects Level 0 parameter?** no — the §1.5 Level 0 row (³P₁/₂–³P₃/₂ detuning, two-photon Rabi rate, allowed scattering rate) and the G3-closure reference triple `{Δ_ref = 40 GHz, Ω_R/2π = 400 kHz, Γ_sc = 2.0 × 10⁴ s⁻¹}` are independent of the doubling-chain hardware photographed here.
- **Affects Level 1 parameter?** no — the page describes *currently fielded* hardware (Raman / BD / RD lines, all already operational) and does not alter the source-side UV-power, beam-quality, or seed-linewidth budgets. The photogrammetric fold-angle reading is *consistent with* the Friedenauer-stated 27.4° within ±5° and does not propose tightening of any Level 1 row.
- **Affects success criterion?** no.

This entry therefore does not require Council-3 deliberation. It is a **lab-asset survey** with a photogrammetric extraction attached.

---

## 1 · Artefacts landed

Three archive-grade top-view photographs of the **Bermuda ²⁵Mg⁺ apparatus** doublers, committed under [`docs/assets/components/home-built-doublers/`](../docs/assets/components/home-built-doublers/):

| File | Original size | Doubler | State at capture |
|---|---|---|---|
| `bermuda-bd-bbo-doubler-2026-05.jpeg` | 2904 × 1489 px | **BD** — blue-Doppler / cooling, 3s S₁/₂ ↔ 3p P₃/₂ | Active; 559-nm scattered light floods the green channel |
| `bermuda-raman-bbo-doubler-2026-05.jpeg` | 3026 × 1615 px | **Raman** — stimulated-Raman gates between 3s S₁/₂ hyperfine ground states | Laser off, clean service view; input λ/2 rotation mount in frame |
| `bermuda-rd-bbo-doubler-2026-05.jpeg` | 4032 × 2447 px | **RD** — red-Doppler / repump, 3s S₁/₂ ↔ 3p P₁/₂ | Laser off, well lit; distinct black-anodised mount style |

The companion components-page surface is [`docs/components/home-built-doublers.md`](../docs/components/home-built-doublers.md) — Charter idiom applied (endorsement marker, Coastline/Sail boundary, G1/G2/G3 status, anti-seeding clause, per-row `O` / `O*` / `OPEN` provenance, cross-walk to `inventory.md` and `friedenauer-baseline.md`).

Cross-references added on the same commit set:

- One-line entry in the home [docs/index.md](../docs/index.md) lookup row.
- "See also" link from [docs/components/friedenauer-baseline.md](../docs/components/friedenauer-baseline.md).
- Scope-paragraph mention in [docs/components/inventory.md](../docs/components/inventory.md).

---

## 2 · What the photographs do — and do not — establish

**Directly observable (`O`-tier):**

- All three doublers implement the **four-mirror bowtie ring** of Friedenauer 2006 §3 (two plane mirrors on the long-arm side — IC M1' and HC-piezo HR M2' — and two concave focusing seats — HR M3' and OC-with-HT-280 M4' — at the crystal waist).
- All three doublers host a **temperature-controlled, water-cooled BBO oven** centred between M3 and M4.
- The Raman-doubler **Hänsch–Couillaud servo seat** is directly visible: the piezo body (coil-wound) is in-frame behind the M2' optic.
- The RD-doubler **HC servo lead** is directly visible: the red insulated cable enters the M2' mount from the upper edge of the frame.
- The Raman doubler carries an **input λ/2 rotation mount** (Thorlabs, graduated 0–360° scale) ahead of the IC.
- The RD doubler uses a **distinct mount-vendor style** (black-anodised bodies, white substrate-side labels reading `HH56` / `HR56` plus `Rück...` — German for *back*) versus the red-anodised kinematic cubes in the BD and Raman doublers. Cavity layout is unchanged; only the optomechanics differ.
- A small flag in the BD-doubler photo carries the partial label `HR@280 HT@56_` (the trailing digit obscured by green glare).

**Partially visible / inferred (`O*`-tier):**

- The BD doubler's **HC servo seat** placement on M2' is *inferred* from the mount footprint and topology (matching Raman / RD); the piezo body itself is occluded by green flooding and the piezo lead is not separable from other cabling in the green-flooded frame.
- The `HR@280 HT@56_` flag in the BD doubler is **flagged for bench verification** because the visible coating direction does *not* match a Friedenauer M4' OC (`HR @ 559 + HT @ 280`); plausible re-readings are (i) the label belongs to an adjacent UV-pickoff dichroic, not the cavity OC, or (ii) it is a service tag pointing to a different element.
- Photogrammetric fold-angle estimate (§3 below) is `O*` *Sail*: ±5° from substrate-centre pixel-identification, not a bench measurement.

**Not in frame / not establishable from these photos (`OPEN`):**

- Input λ/2 plate (or equivalent polarisation-conditioning optic) for the **BD and RD doublers** — presumed by analogy with the Raman doubler and the *de facto* requirement of any Brewster-cut-BBO cavity, but **not photographed**.
- Coating identities (R-values at 559 nm / T-values at 280 nm) on any fielded mirror.
- BBO-crystal lot per doubler (Raicol 2025 / A-Star 2017 / Castech 2009 from on-shelf inventory, or a lot not in the inventory at all).
- Piezo make / model and HC servo-loop bandwidth (the Friedenauer-stated ~18 kHz loaded-piezo resonance is the cross-cavity reference number; per-doubler measurement is OPEN).
- BBO-oven manufacturer / set-point / stability.
- UV-output power, beam quality, polarization, and drift at each doubler.
- Bench-grade fold angle to ±1° (the photogrammetric ±5° band in §3 is `O*`, not `O`).

---

## 3 · Photogrammetric fold-angle extraction (this work)

**Why this matters.** Friedenauer 2006 §3 states a "full folding angle 27.4°" with "13.7° per focusing mirror" for the BBO ring. Before today, the components-page row for fold angle was tagged `OPEN` ("compatible with the 27.4° full fold but `OPEN` from this view alone"). The photographs do permit a reading — at lower precision than a bench protractor, but enough to resolve "bowtie compatible with Friedenauer" from "wider / squarer" or "tighter" alternative geometries.

**Method.** For each archived JPEG at original resolution, I read off mirror-substrate pixel centres on the four kinematic mounts (M1, M2 plane; M3, M4 curved), then computed at each curved-mirror vertex the angle between (i) the incoming long-arm vector (M1→M3 or M4→M2) and (ii) the outgoing short-arm vector (M3→M4). In a symmetric bowtie this V-opening is Friedenauer's "full folding angle". The X-cross apex (angle between the two long arms at their crossing point in the upper half of the cavity) was computed as a cross-check; in a symmetric bowtie X-apex = 2 × full fold.

**Result.** *Sail* — observational, not a binding parameter. Uncertainty ±5°, dominated by ±20–50 px identification of mirror-substrate centres on each kinematic mount; not by mount-style differences.

| Doubler | Fold at M3 | Fold at M4 | Mean ±5° | X-cross apex | vs Friedenauer 27.4° |
|---|---|---|---|---|---|
| **BD** (green-flooded) | 26.6° | 25.6° | **26°** | 52.2° | within ±2° |
| **Raman** (clean) | 30.5° | 28.0° | **29°** | 58.5° | within ±2° |
| **RD** (clean, black mounts) | 27.4° | 23.1° | **25°** | 50.5° | within ±3° |

**Headline.** All three doublers are built to a Friedenauer-equivalent ~27° full fold within the photogrammetric ±5° band. No doubler reads as a square-ring (45°) or wide bowtie (>35°); none reads tighter than ~20°. The 4° spread between the three mean values **is not resolved as a real build-to-build difference** from these photographs alone — bench measurement to ±1° would close it.

**M3–M4 asymmetry within each doubler.** A 2–4° gap between M3 and M4 V-openings appears in every doubler; this is comparable to the ±5° pixel-identification budget and is best read as photogrammetric noise, not a cavity-asymmetry signal. In the RD doubler the M4 substrate centre is harder to read than the others because the mount face is partly in shadow.

---

## 4 · Errata caught during the work

A labelling swap I introduced in the first draft of [`docs/components/home-built-doublers.md`](../docs/components/home-built-doublers.md): the green-flooded operating photo was titled "Raman" and the clean service view was titled "BD", which is the opposite of what the desktop filenames pin (`bermuda BD BBO doubler_2026_05.jpeg` is the green-flooded one; `bermuda Raman BBO doubler_2026_05.jpeg` is the clean one). The pixel-dimension check (BD = 2904 × 1489; Raman = 3026 × 1615; RD = 4032 × 2447) confirmed the swap.

Fixed in the same commit set: section titles (B.1 Raman → BD, B.2 BD → Raman), image alt-text, image-file references, the per-doubler function blurbs (cooling vs Raman-pair), the HBD-R-* and HBD-BD-* table prefixes (all swapped consistently across §B and §C of the page), and the §C cross-walk row that pairs "piezo directly visible" / "occluded by green flooding" with the right doubler. The RD doubler was unaffected.

This errata note is recorded here so a future reader who sees the page after the fix can still trace the correction trail.

---

## 5 · Charter compliance

**Anti-seeding boundary.** This page is an observational record of *currently fielded* hardware. It belongs to Phase 1 in the sense of an admissible literature-equivalent artefact (`docs/principles.md` "Anti-seeding clause" — Phase 1 dossier population is unblocked; architecture-family-specific simulation in `/src/` is forbidden until G1 closes). The page introduces no new architecture preset, no new simulation code, no new parameter constant. It is therefore admissible in its current form.

**Gate status.** G3 closed 2026-05-01; the reference triple is unaffected by today's entry. G1 (14-GHz unlockable-domain attribution) and G2 (UV-induced degradation at 280 nm) remain open and are not advanced by this entry.

**Provenance tier.** Every observation in [`docs/components/home-built-doublers.md`](../docs/components/home-built-doublers.md) carries an `O` / `O*` / `OPEN` tag in the per-doubler tables, consistent with the convention established in [`docs/components/inventory.md`](../docs/components/inventory.md). The photogrammetric fold-angle extraction is reported with an explicit ±5° uncertainty band derived from the pixel-identification budget; this is observational *Sail* guidance, not a binding *Coastline* parameter.

**Asymmetric erosion protection.** No tightening or relaxation of a Level 0 / Level 1 parameter is proposed. Nothing on this page weakens any committed CHARTER row.

---

## 6 · Suggested follow-on (out of scope of this entry)

In priority order for closing the `O*` / `OPEN` items above:

1. **Close-up of each substrate side-label** in the RD doubler (M1, M2, M3, M4) — the white substrate-side labels (`HH56` / `HR56` / `Rück...`) are the highest-information-density artefact in the three photographs and the RD photo has the best resolution to read them.
2. **Close-up of the `HR@280 HT@56_` flag** in the BD doubler to disambiguate cavity-element vs external-pickoff identity.
3. **Side or oblique view of each crystal oven** to read the oven manufacturer / part number / set-point label (if any).
4. **In-frame ruler photo** (or a calibration shot of the breadboard hole pattern under the same camera position) to lift the breadboard-hole-pitch scale uncertainty and let the cavity round-trip length be read off to ±5 % instead of "consistent with 0.4–0.5 m".
5. **Bench protractor / theodolite measurement** of the full folding angle on at least one of the three doublers, to anchor the photogrammetric reading to ±1° instead of the present ±5° band.
6. **Per-doubler UV-output measurement** (power, beam quality, polarization, drift) — these are operational quantities, not geometric features, and are downstream of the next-gen workplan ([`logbook/2026-05-08-next-gen-500mW-workplan.md`](2026-05-08-next-gen-500mW-workplan.md)).

---

## 7 · See also

- [`docs/components/home-built-doublers.md`](../docs/components/home-built-doublers.md) — companion components-page surface.
- [`docs/components/friedenauer-baseline.md`](../docs/components/friedenauer-baseline.md) — published BBO-ring specification that the three fielded doublers are direct topological relatives of.
- [`docs/components/inventory.md`](../docs/components/inventory.md) — on-shelf stock cross-walked in §C of the components page.
- [`docs/components/seed-lasers.md`](../docs/components/seed-lasers.md) — upstream VECSEL source-class direction (the seed feeds these doublers).
- [`logbook/2026-05-08-next-gen-500mW-workplan.md`](2026-05-08-next-gen-500mW-workplan.md) — the doubling-chain workplan that may take one of the fielded doublers as a candidate physical seat for the next-gen 500 mW build.
- [`logbook/2026-05-08-vecsel-seed-lasers.md`](2026-05-08-vecsel-seed-lasers.md) — companion steward direction on the seed-laser layer.

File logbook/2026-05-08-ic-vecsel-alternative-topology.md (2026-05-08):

# Alternative next-gen topology — IC-VECSEL with intracavity LBO + free-space PDH-locked BBO in a sealed 19" rack envelope

**Steward:** Ulrich Warring
**Date:** 2026-05-08
**Status:** SKETCH (architecture exploration; no build commitment, no `/src/` code)

## Header (Charter §9 trigger questions)

- **Affects Level 0 parameter?** no — reference triple `{Δ_ref = 40 GHz, Ω_R/2π = 400 kHz, Γ_sc = 2.0 × 10⁴ s⁻¹}` (locked at G3 closure 2026-05-01) is unaffected.
- **Affects Level 1 parameter?** **Conditional, paired-architecture only.** As a stand-alone option this sketch *cannot* meet the CHARTER §1.5 indicative anchor of ≥ 500 mW UV at 280 nm — the §1a task-scoping shrinks the chain to ~ 50 mW UV (~ 500 mW visible at the BBO input). The reduced UV target is **valid only as a paired task allocation** with the [pulsed-Raman alternative](2026-05-08-pulsed-raman-alternative-topology.md), which would carry the Raman-task power requirement at a separate operating point. Without that pairing (or an equivalent off-board Raman pathway), this sketch underdelivers Level 1 and would not be admissible as a single-architecture candidate.
- **Affects success criterion?** Conditional — same paired-architecture framing as Level 1.

This entry sits **alongside** the [next-gen 500 mW workplan](2026-05-08-next-gen-500mW-workplan.md), which optimises parameters *within* the Friedenauer two-cavity topology. The present sketch proposes a **different topology** — to be evaluated as a Phase 4 architecture-comparison candidate once G1 and G2 close. The anti-seeding clause (`docs/principles.md` §5.1) is in force throughout: no `/src/architecture/` code follows from this sketch.

---

## 1 · Concept in one sentence

Replace the three-cavity Friedenauer chain (Yb-fibre seed → LBO ring → BBO ring) with **two cavities only** — an **intracavity-doubled VECSEL** whose linear cavity contains an LBO crystal producing 559 nm directly out of the gain-mirror cavity, plus a **free-space PDH-locked BBO ring** in tight integration — all sealed inside a temperature-controlled, evacuated-or-inert-gas-purged 19" rack envelope.

## 1a · Task scope and revised power target *(steward direction 2026-05-08, corrected 2026-05-08)*

This option is sized for **cooling and repumping only**. The Raman-task power requirement is offloaded to the [pulsed-Raman alternative](2026-05-08-pulsed-raman-alternative-topology.md) (a separate far-red-detuned mode-locked-comb pathway), so the **UV** power target for *this* chain shrinks from the CHARTER §1.5 indicative anchor (≥ 500 mW for the all-in-one chain) to the cooling-and-repumping-only requirement of **~ 50 mW @ ~ 280 nm**.

The visible-stage requirement does **not** shrink proportionally. The BBO buildup cavity at the in-house operating point converts only ~ 10 % of input visible to UV: [Guth21] §3.4 measured 78(5) mW UV from 780(15) mW visible (10.0(11) %); [Frie06] reports ≥ 100 mW UV from 1.4 W visible (~ 7 %). To deliver 50 mW UV the BBO ring must therefore see **~ 500 mW @ 559 nm** at its input. The implied stage-by-stage budget for this sketch is therefore:

- **IC-VECSEL direct output:** ~ 500 mW @ 559 nm (intracavity-doubled).
- **BBO ring input:** ~ 500 mW @ 559 nm (free-space, after isolator + EOM, no fibre loss).
- **BBO ring output (UV):** ~ 50 mW @ ~ 280 nm at ~ 10 % visible-to-UV.

The visible-output-scaling question therefore remains the dominant open-question concern for the IC-VECSEL topology at this operating point. [Burd16] reported ~ 30–80 mW direct visible from the 1117 nm IC topology; extending this to ~ 500 mW is a ~ 5–10× scaling step that is the principal numerical target of the open `shg_intracavity.py` notebook exploration listed in §10. At the W-class intracavity IR circulation consistent with [Span25] gain-mirror operating points, ~ 500 mW direct intracavity-doubled visible at 559 nm is achievable in principle (industrial DPSS-green intracavity-LBO at 532 nm at multi-W is mature in adjacent fields) — but is **not directly demonstrated** for the 1118 nm operating point and depends on gain-mirror MBE specification, intracavity LBO geometry, and the dichroic-outcoupler design.

What does relax at the 50 mW UV target:

- The UV-side operating point ≤ 50 mW sits comfortably below typical CW BBO LIDT bounds ([Eime87], [Turc22]) and within the surface-contamination-limited regime where [Burk21]-style atmosphere control is the effective lever.
- BBO mirror coatings, crystal length, and waist can be chosen for *operational longevity* rather than peak conversion efficiency — there is no need to push BBO into the depleted-pump regime.
- Sensitivity to BBO efficiency is high: if hard-fluoride coatings ([Burk21]) plus tighter waist push the BBO to 20–30 % visible-to-UV (a 2–3× improvement above the [Guth21] / [Frie06] envelope), the IC-VECSEL visible target relaxes proportionally to ~ 170–250 mW — squarely inside the [Burd16] precedent envelope.

In Charter terms this is *not* a relaxation of the reference triple — Level 0 (Δ_ref, Ω_R, Γ_sc) and Level 1 (UV at experiment input, beam quality, source linewidth) for the cooling-and-repumping task are unaffected. What changes is the **task allocation between architectures**: cooling+repumping → this CW chain at ~ 50 mW UV (~ 500 mW visible); Raman → pulsed-comb chain at the red-detuned operating point. The 500 mW UV anchor of CHARTER §1.5 was a single-architecture figure; the slate-of-three approach decomposes it.

## 2 · Topology sketch

```
[ TEMPERATURE-CONTROLLED, VACUUM / N2 / Ar-PURGED 19-INCH RACK ENVELOPE ]

  808 nm pump fibre
        │
        ▼
  ┌──────────────────────────────────────────┐
  │  IC-VECSEL CAVITY (single cavity)        │
  │                                          │
  │  Vexlum gain mirror ──┐                  │
  │       (1118 nm)        │                 │
  │                        │                 │
  │  ┌───────────────┐     │                 │
  │  │ BRF (Newlight)│     │                 │
  │  └───────────────┘     │                 │
  │  ┌───────────────┐     │                 │
  │  │ Etalon (LM)   │     │                 │
  │  └───────────────┘     │                 │
  │  ┌───────────────┐     │                 │
  │  │ Intracavity   │  high-IR                │
  │  │ LBO crystal   │  circulation           │
  │  │ Type-I NCPM   │  (~ 100 W class)       │
  │  │ ~ 150 °C oven │     │                 │
  │  └───────────────┘     │                 │
  │  ┌───────────────┐     │                 │
  │  │ Dichroic OC:  │     │                 │
  │  │ HR @1118 nm   │     │                 │
  │  │ HT @559 nm    │     │                 │
  │  └───────────────┘                       │
  │       │                                  │
  │       ▼                                  │
  │  ~ 500 mW @ 559 nm direct out            │
  │  (BBO ~ 10 % visible-to-UV per           │
  │   [Guth21] / [Frie06])                   │
  └───────┼──────────────────────────────────┘
          │
          ▼   Optical isolator (visible, vacuum-compatible)
          │
          ▼   EOM — PDH sideband generator @ 10 – 50 MHz
          │
  ┌───────┼──────────────────────────────────┐
  │  FREE-SPACE BBO RING BUILDUP CAVITY      │
  │                                          │
  │  Brewster-cut β-BBO, Type-I CPM          │
  │  Hard fluoride coatings ([Burk21])       │
  │  PDH lock — error signal from cavity     │
  │  reflection, demodulated against EOM     │
  │  drive frequency                         │
  └────────────────────┼─────────────────────┘
                       ▼
                ~ 50 mW @ ~ 280 nm
                (cooling + repumping target;
                 Raman task moves to pulsed alternative)
```

## 3 · What carries over from the steward direction

- VECSEL is the seed-laser source class per the steward direction recorded 2026-05-08 ([logbook entry](2026-05-08-vecsel-seed-lasers.md), components page [`docs/components/seed-lasers.md`](../docs/components/seed-lasers.md)).
- Class-A laser dynamics, intracavity BRF + 1 mm YAG etalon + PZT mode selection, diamond-bonded Vexlum gain mirror — all per [Burd23] design principles.
- In-house BOM continuity from [Kief20] / [Guth21] / [Span23] / [Span25]: Vexlum gain mirror, Newlight BIR0030 BRF, LightMachinery OP-3167-1000 etalon, Ostech 808 nm pump.
- Dry-gas (or vacuum) purge of the laser envelope per [Burd23] §2 and [Burk21].

## 4 · What changes vs the Friedenauer baseline and the existing next-gen workplan

| Element | [Frie06] baseline | Existing [next-gen workplan](2026-05-08-next-gen-500mW-workplan.md) | This alternative sketch |
|---|---|---|---|
| Task scope | All UV tasks (cooling, repumping, Raman, photoionisation) | All UV tasks | **Cooling + repumping only; Raman handled by [pulsed alternative](2026-05-08-pulsed-raman-alternative-topology.md)** |
| UV power target | ~ 0.275 W (as published) | ≥ 500 mW (Charter §1.5 anchor) | **~ 50 mW (cooling + repumping only)** |
| Seed → visible | Yb-fibre 1118 nm → LBO ring (HC-locked) | VECSEL 1118 nm → LBO ring (HC-locked) | **IC-VECSEL with intracavity LBO; no external visible buildup cavity** |
| Visible → UV | BBO ring (HC-locked) | BBO ring (HC-locked) | **BBO ring (PDH-locked, EOM-modulated)** |
| Cavity count | 3 | 3 | **2** |
| Stage-to-stage coupling | Fibre | Free space | **Free space, tightly integrated** |
| Atmosphere | Lab air | Lab air (TEC-stabilised) | **Vacuum or N2 / Ar purge** |
| Form factor | Optical table | A4 + 19" rack ([Span25]) | **Single sealed 19" rack box** |

## 5 · Coastline claims *(testable design constraints inherited from precedent)*

- **Intracavity-doubled VECSEL at this wavelength is precedented.** [Burd16] demonstrated an IC-VECSEL at 1117 nm producing 558.5 nm intracavity-doubled output (then externally to 280 nm) in the same NIST + Tampere collaboration that anchors [Burd23]. The IC topology is not exotic; the 1 nm offset to 1118 nm is well within the gain-mirror MBE tolerance.
- **PDH on a deep-visible BBO cavity is precedented and higher-bandwidth than HC.** [Burd23] §3 used PDH on the first-stage PPKTP enhancement cavity at 940 nm precisely because the dispersive PDH error signal survives depleted-pump conditions that stress the polarisation-sensitive Hänsch-Couillaud signal. The cost is one EOM at 559 nm and demodulation electronics.
- **UV-induced contamination is mitigated by atmosphere control.** [Burk21] demonstrated stable deep-UV enhancement-cavity operation in UHV with hard fluoride mirror coatings; [Brow19] showed surface contamination is the dominant LIDT precursor, not bulk-crystal LIDT ([Eime87] [Turc22]). Sealing the envelope closes this channel architecturally.

## 6 · Sail recommendations *(adaptive guidance, contextual to this sketch)*

- **Type-I non-critical phase-matched (NCPM) LBO at ≈ 150 °C** inside the VECSEL cavity — eliminates walk-off and matches the high intracavity beam-quality requirement; thermal load handled by an isolated oven mount that does not couple back into the gain-mirror Peltier.
- **Hard fluoride mirror coatings** on the BBO ring per [Burk21]; oxide IBS coatings degrade faster under deep-UV.
- **Raspberry-Pi-based controller** ([Span25] precedent) handles VECSEL TECs *and* BBO PDH demodulation in software at the < 100 kHz cavity-lock bandwidth — extending the [Span25] cost / integration profile.
- **Rough vacuum (1–10 mbar)** preferred over inert-gas purge if vacuum-compatible EOM and isolator are sourced; otherwise N2 or Ar purge with clean-gas plumbing through the rack envelope.

## 7 · Tradeoffs vs the existing next-gen workplan

**Pros**

- **One fewer cavity-lock loop** — the external LBO buildup cavity goes away; only the BBO cavity is locked.
- **No fibre between stages** — eliminates the 20–25 % fibre-coupling loss observed in [Guth21] Table 8.
- **Tight integration in single envelope** — reduces inter-stage alignment drift, mechanical-noise pickup, and air-path contamination.
- **G2 mitigation is architectural, not just operational** — the sealed envelope addresses UV-induced degradation at the design level rather than via cleanliness procedures.

**Cons / open questions**

- **Intracavity-LBO ↔ gain-mirror thermal coupling.** Both elements share one cavity; the LBO oven (~ 150 °C, NCPM Type-I) and the gain-mirror Peltier (~ 20 °C) need careful thermal isolation. No precedent in the in-house chain; needs notebook simulation before sweeping.
- **Visible-output scaling — remains the dominant open-question concern.** Even at the cooling-and-repumping-only UV target of 50 mW, the BBO buildup cavity's ~ 10 % visible-to-UV efficiency at the in-house operating point ([Guth21] 78(5) mW UV from 780(15) mW visible; [Frie06] ≥ 100 mW UV from 1.4 W visible) drives a ~ 500 mW @ 559 nm requirement at the BBO input. [Burd16] reported ~ 30–80 mW direct visible from the 1117 nm IC topology; extending this to ~ 500 mW is a ~ 5–10× scaling step. Sensitivity to BBO efficiency is high — if hard-fluoride coatings ([Burk21]) plus tighter waist push BBO to 20–30 % visible-to-UV, the visible target relaxes to ~ 170–250 mW, inside the [Burd16] envelope.
- **PDH at 559 nm adds RF.** EOM drive at 10–50 MHz and demodulation electronics inside the rack envelope add RF-noise-pickup risk; shielding and grounding need design.
- **Vacuum / purge plumbing in 19" rack.** Sealed envelope adds feedthrough complexity (pump fibre, PDH error-signal cable, TEC controllers, gas line). N2 / Ar flow is simpler but consumes gas.
- **Phase 4 axis 6 (complexity)** trades *cavity count* for *envelope complexity* — net axis-6 score not obvious without explicit scoring.

## 8 · Anti-seeding clause / G1-G2-G3 boundaries

- **No `/src/architecture/` code.** All numerics for this alternative live in `/notebooks/exploration/` per CHARTER §5.1. The architecture-neutral primitive set (`shg_cascade.py`, `enhancement_cavity.py`, `boyd_kleinman.py`) covers the BBO stage; **intracavity SHG would need a new architecture-neutral primitive** (e.g. `shg_intracavity.py`) before any parameter sweep on this candidate is meaningful.
- **G1 (14 GHz unlockable resonance).** Independent of topology choice; this sketch does not advance G1 closure.
- **G2 (UV-induced degradation).** The sealed envelope is a *candidate* G2 mitigation, but G2 closure requires *measurement* in Phase 2, not architecture choice. This sketch does not close G2.
- **G3 (reference triple).** Locked 2026-05-01; unaffected.
- **Phase 4 architecture comparison.** This candidate joins the slate alongside the existing-next-gen Friedenauer-topology + the named alternatives (PPLN-MgO, PPKTP, single-pass UV with buildup only at 559 nm). Slate is opened *after* G1 and G2 close.
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

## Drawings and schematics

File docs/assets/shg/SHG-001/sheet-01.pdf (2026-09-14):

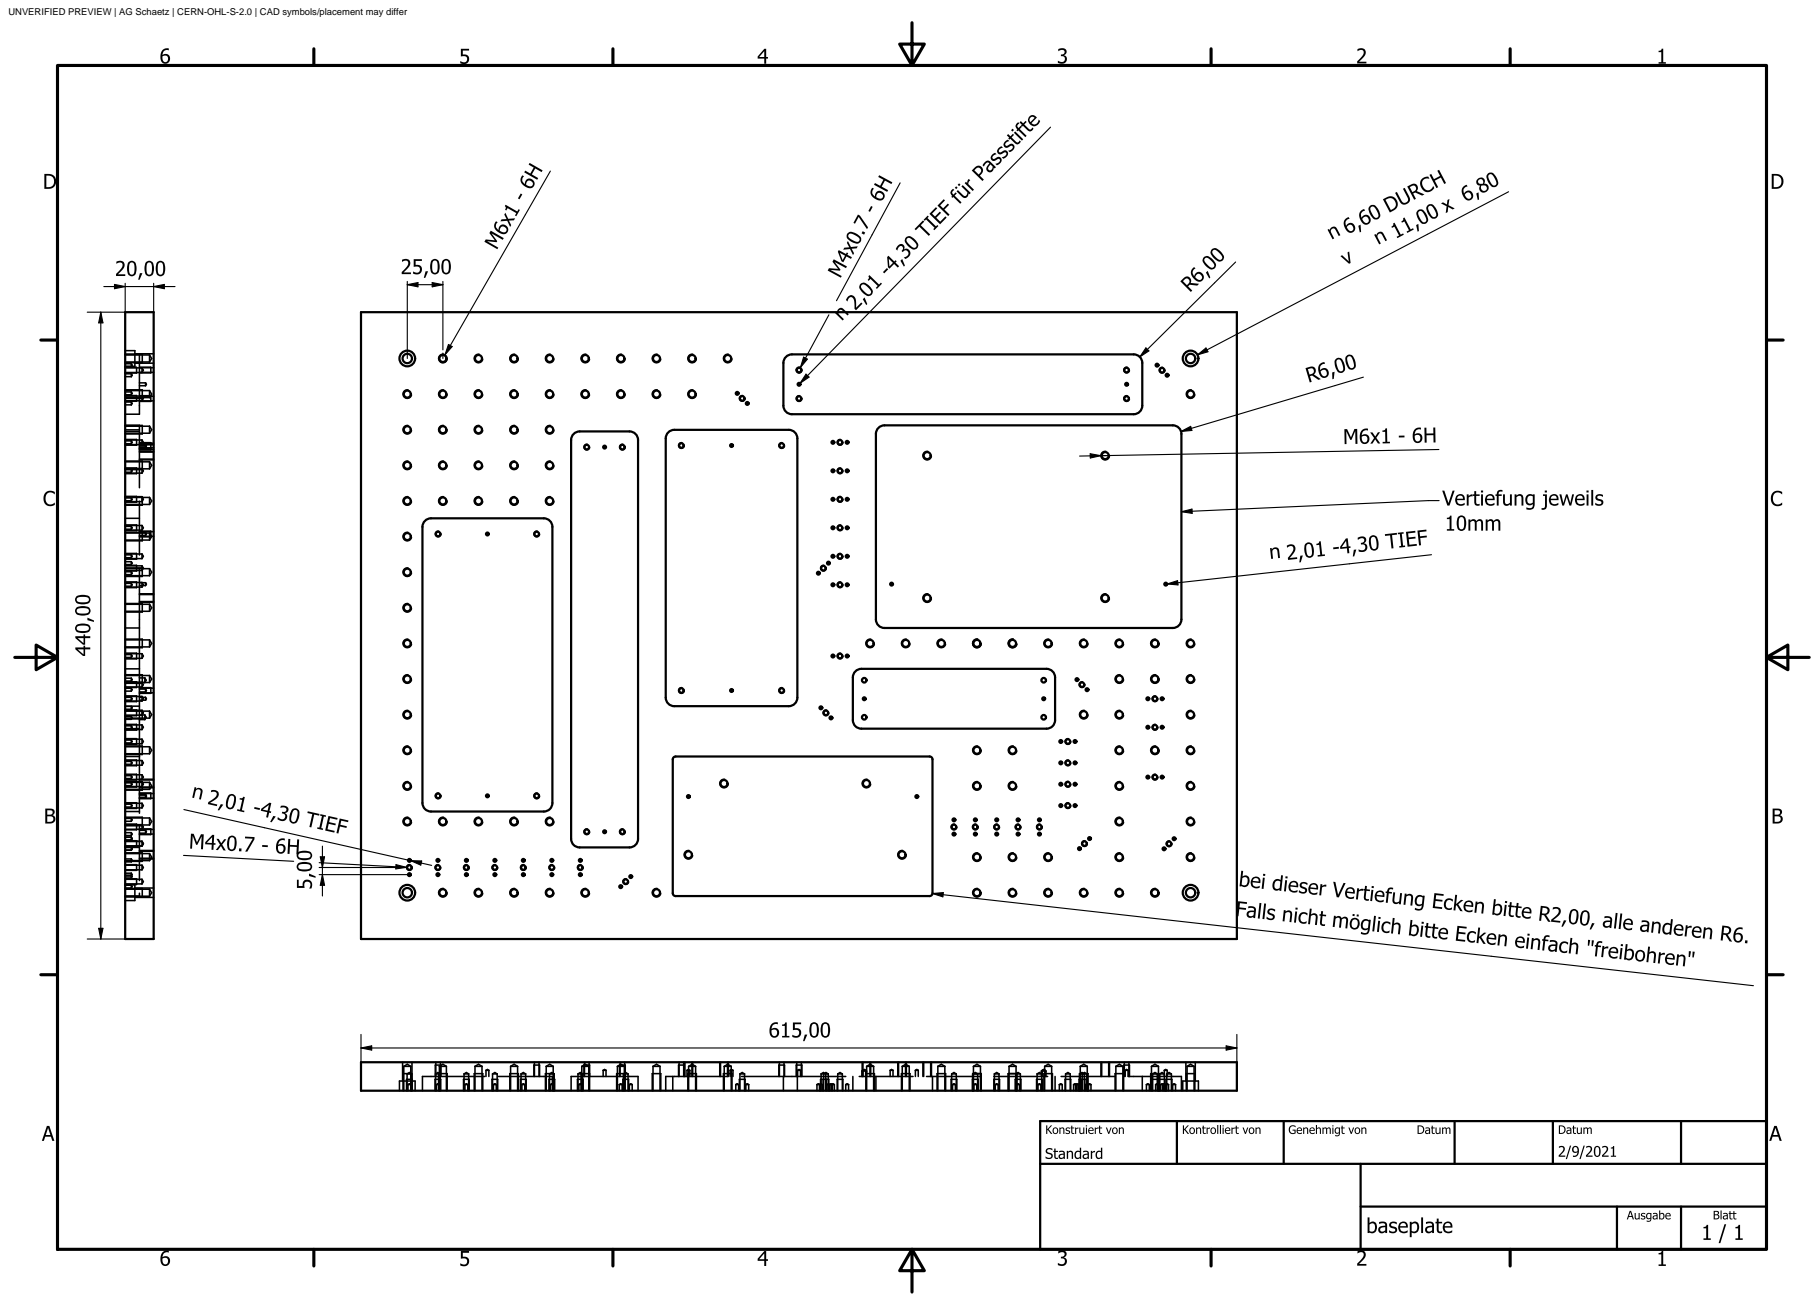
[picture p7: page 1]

UNVERIFIED PREVIEW | AG Schaetz | CERN-OHL-S-2.0 | CAD symbols/placement may differ

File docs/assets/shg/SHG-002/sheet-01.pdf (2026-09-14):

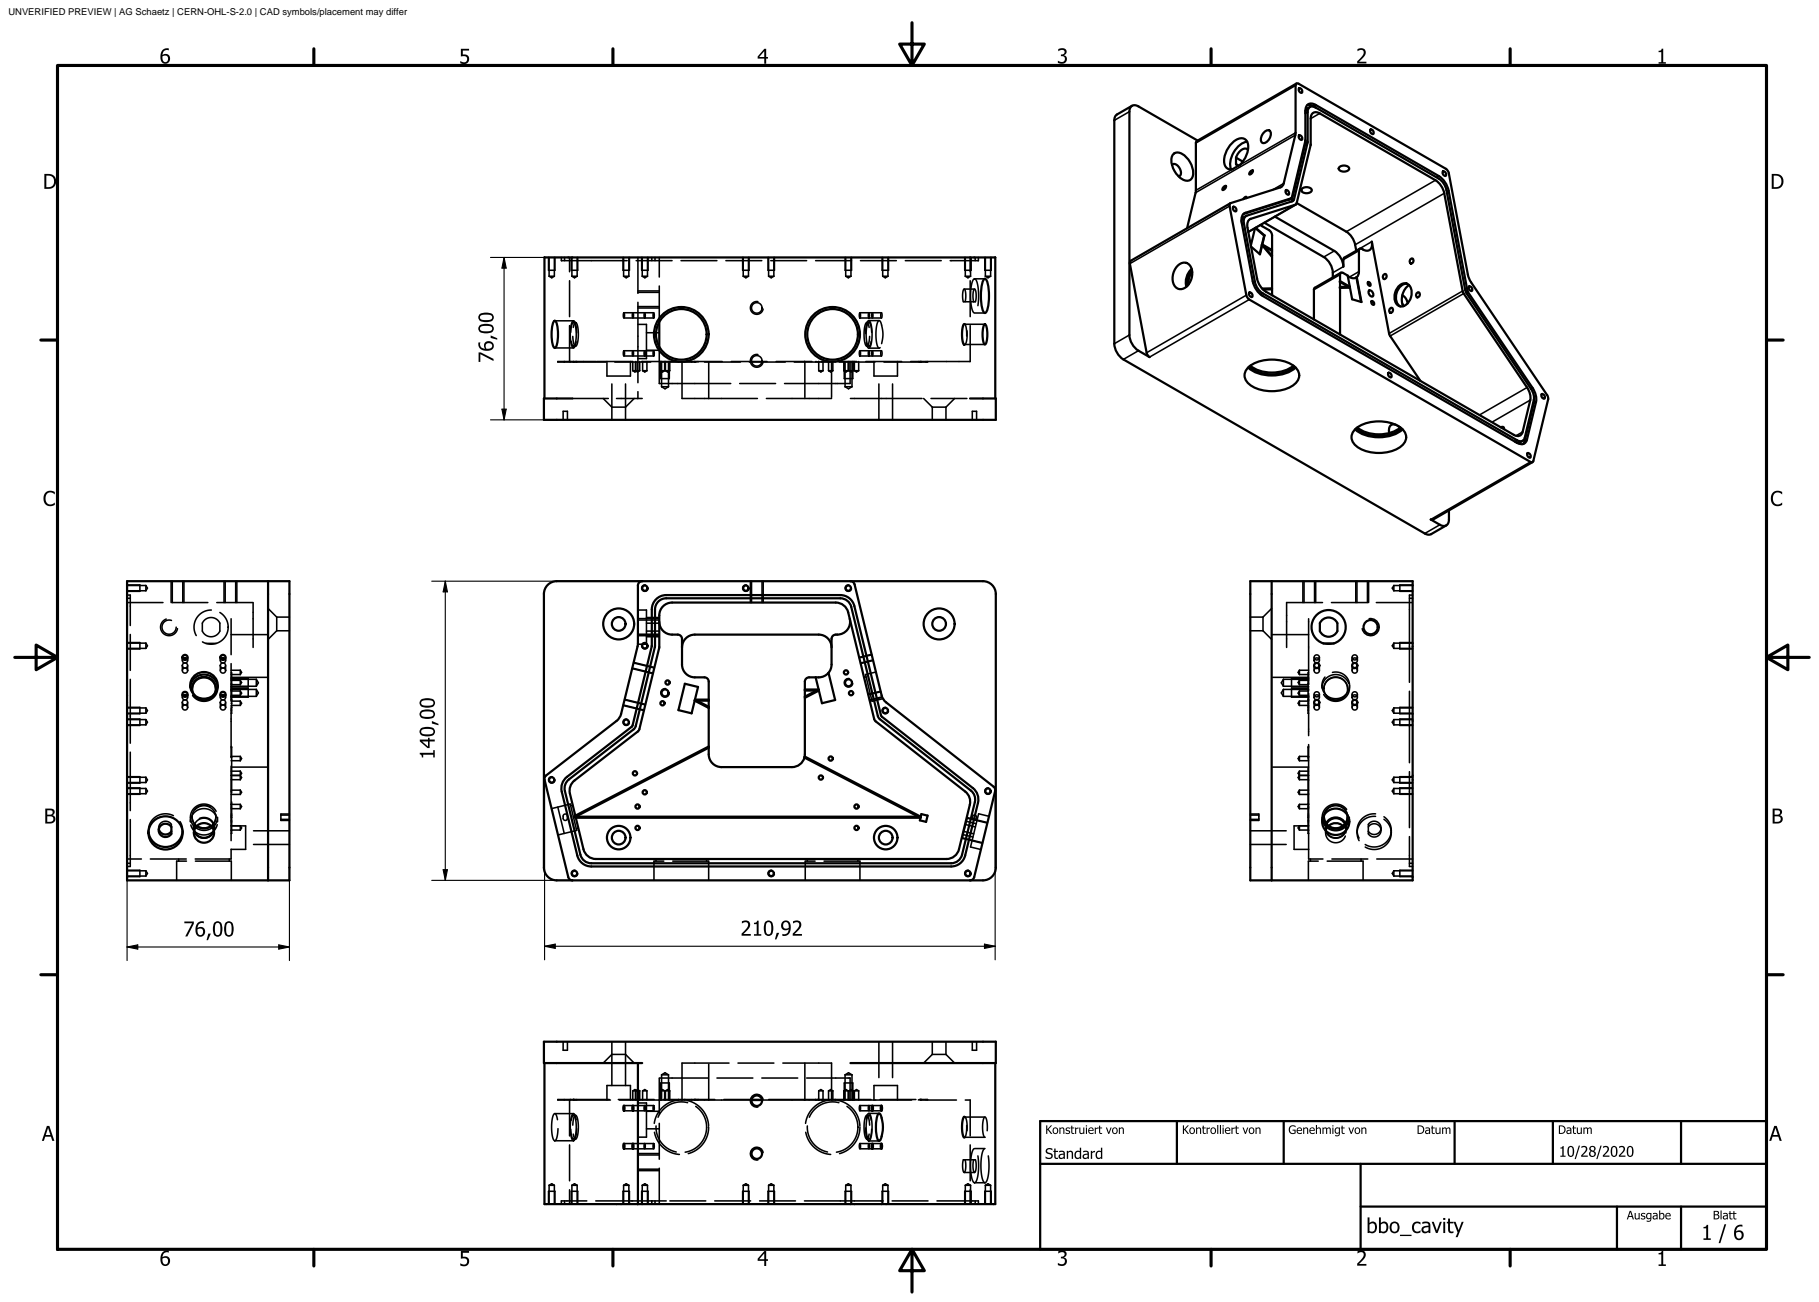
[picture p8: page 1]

UNVERIFIED PREVIEW | AG Schaetz | CERN-OHL-S-2.0 | CAD symbols/placement may differ

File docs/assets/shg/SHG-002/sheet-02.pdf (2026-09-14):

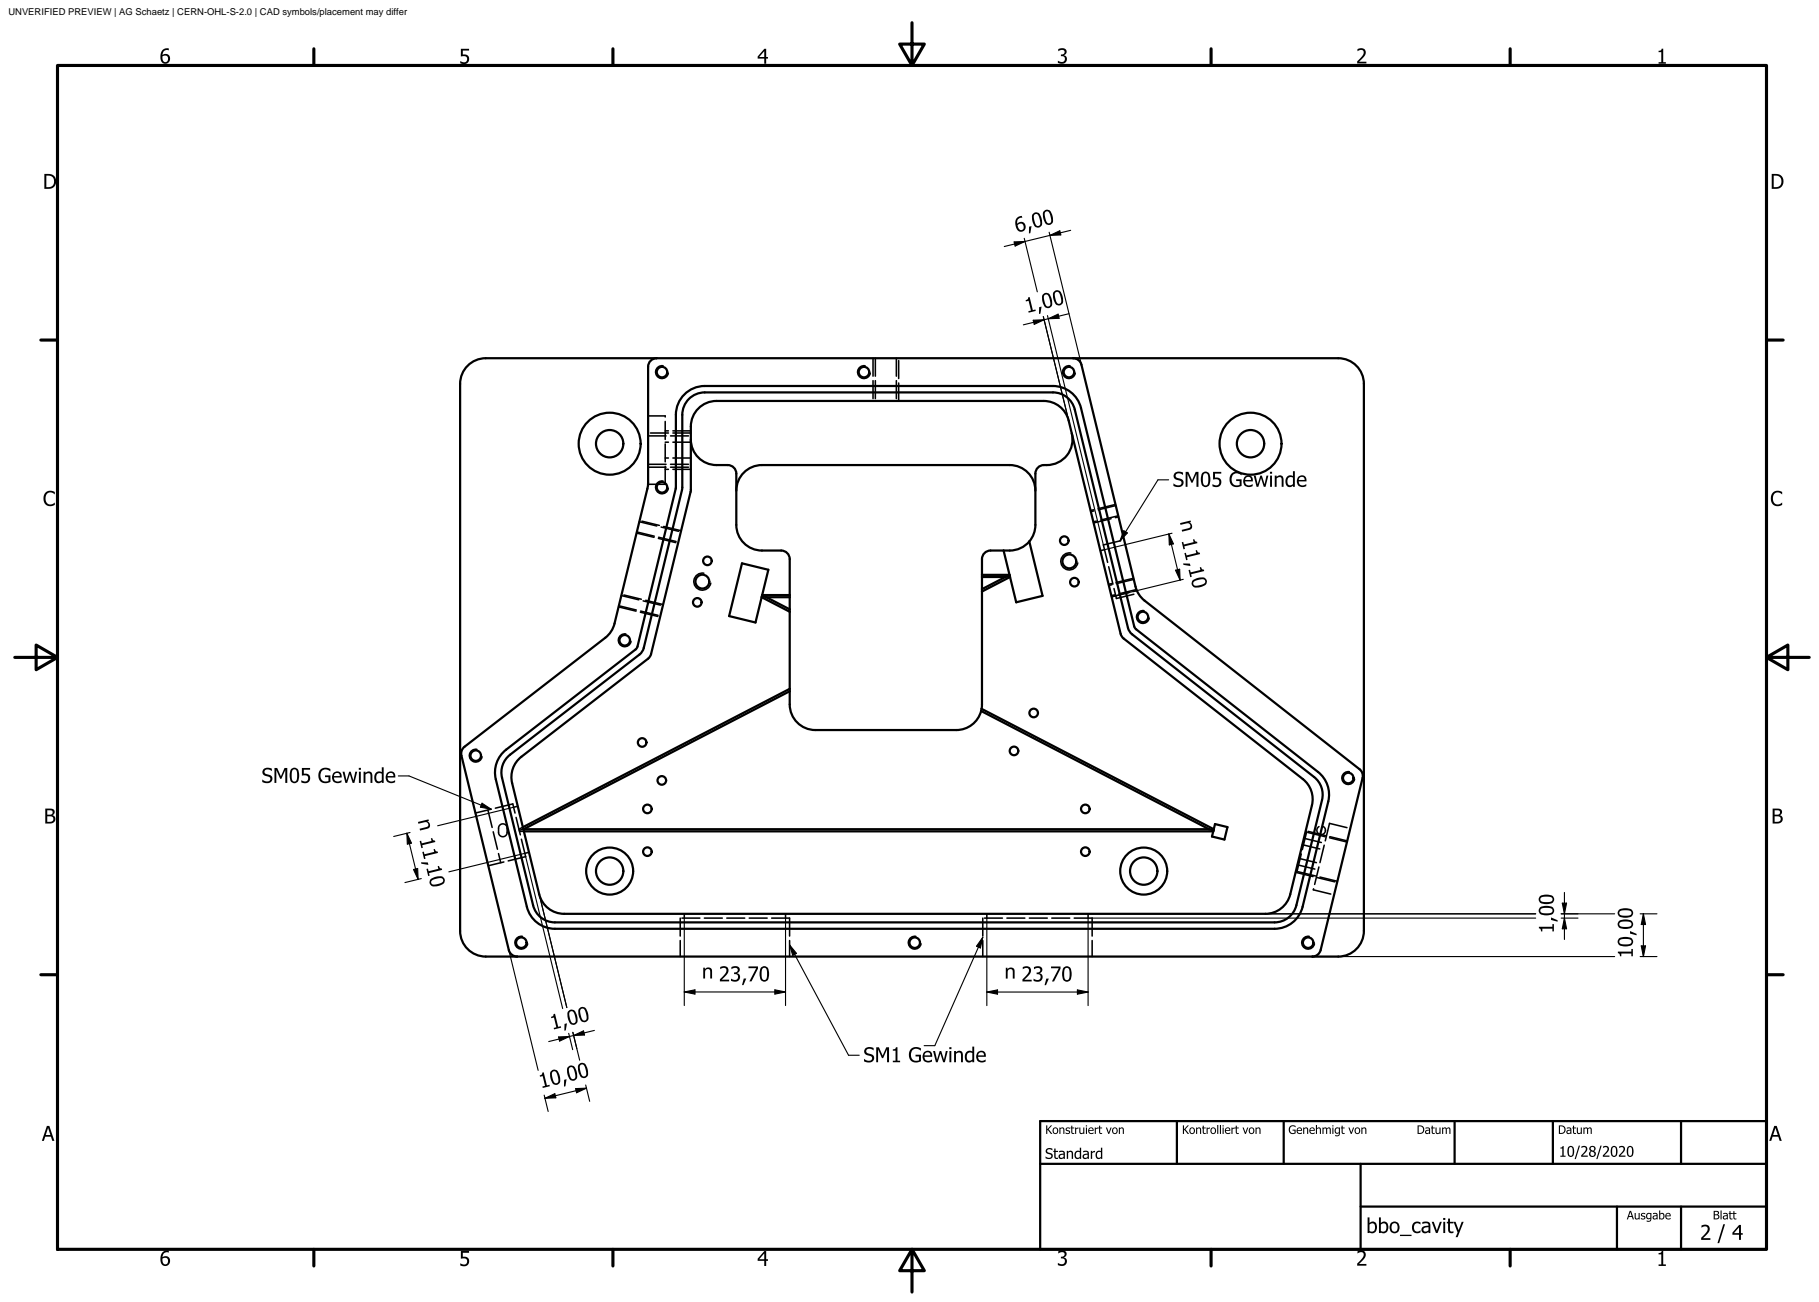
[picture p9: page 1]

UNVERIFIED PREVIEW | AG Schaetz | CERN-OHL-S-2.0 | CAD symbols/placement may differ

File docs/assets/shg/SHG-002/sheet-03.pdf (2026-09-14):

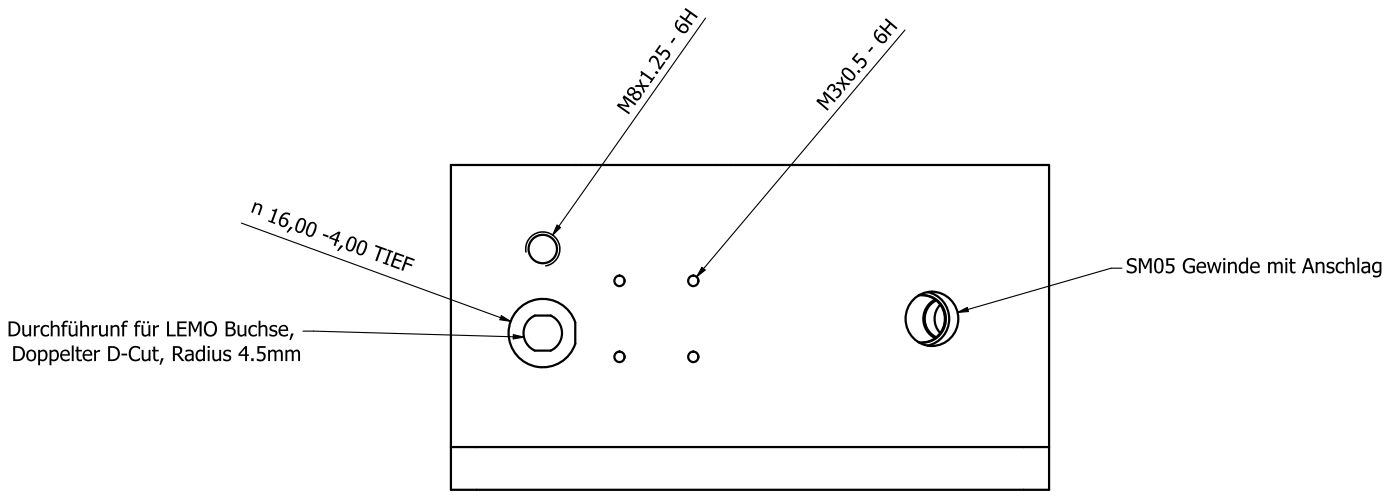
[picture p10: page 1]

UNVERIFIED PREVIEW | AG Schaetz | CERN-OHL-S-2.0 | CAD symbols/placement may differ

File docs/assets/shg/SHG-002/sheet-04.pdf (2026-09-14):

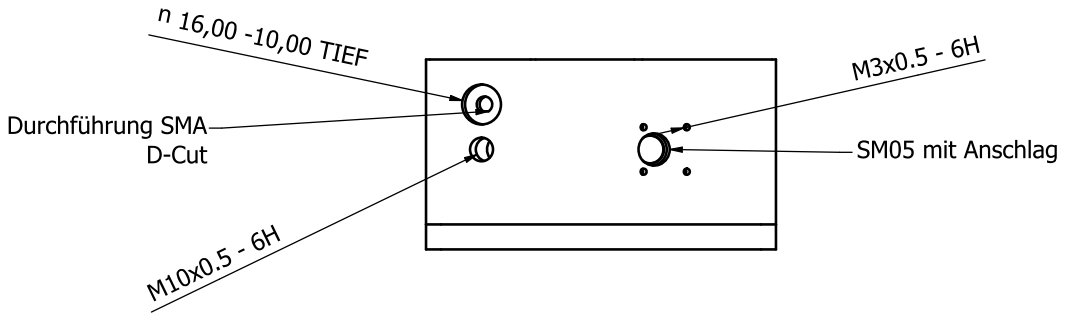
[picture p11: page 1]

UNVERIFIED PREVIEW | AG Schaetz | CERN-OHL-S-2.0 | CAD symbols/placement may differ

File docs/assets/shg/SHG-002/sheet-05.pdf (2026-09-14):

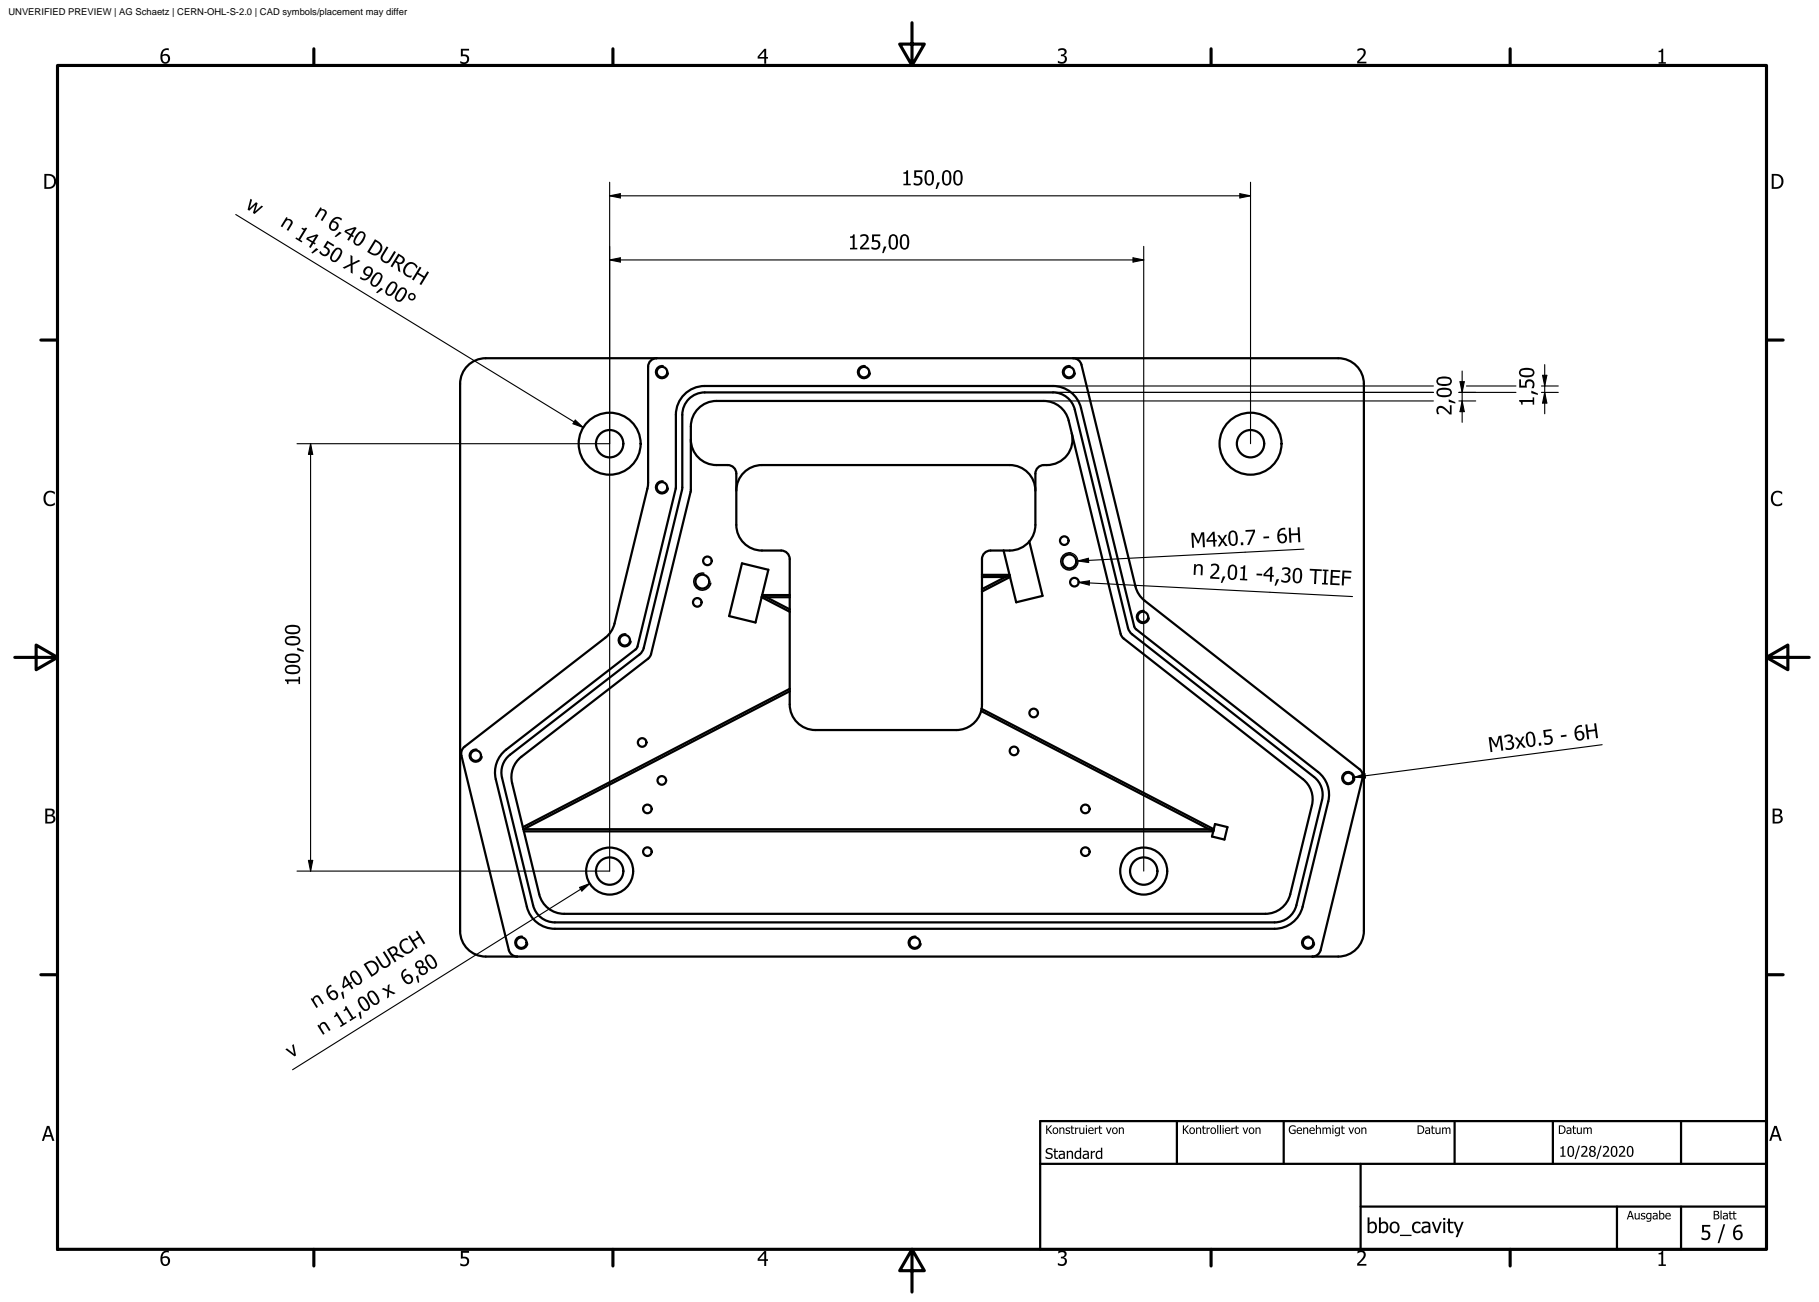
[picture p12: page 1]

UNVERIFIED PREVIEW | AG Schaetz | CERN-OHL-S-2.0 | CAD symbols/placement may differ

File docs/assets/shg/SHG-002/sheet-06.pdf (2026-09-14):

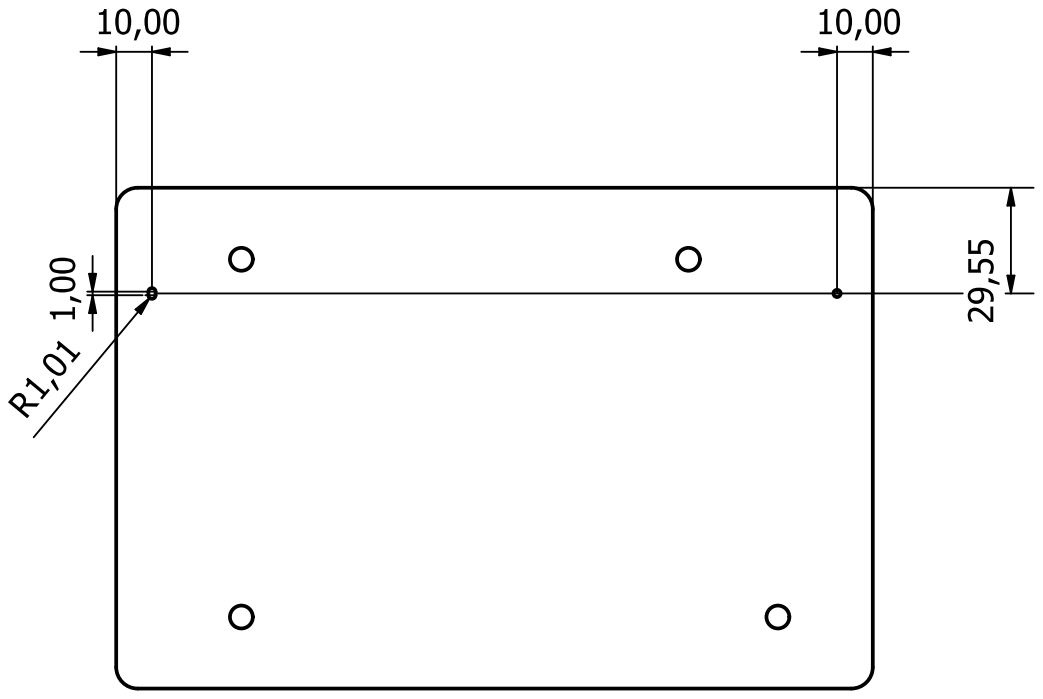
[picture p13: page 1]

UNVERIFIED PREVIEW | AG Schaetz | CERN-OHL-S-2.0 | CAD symbols/placement may differ

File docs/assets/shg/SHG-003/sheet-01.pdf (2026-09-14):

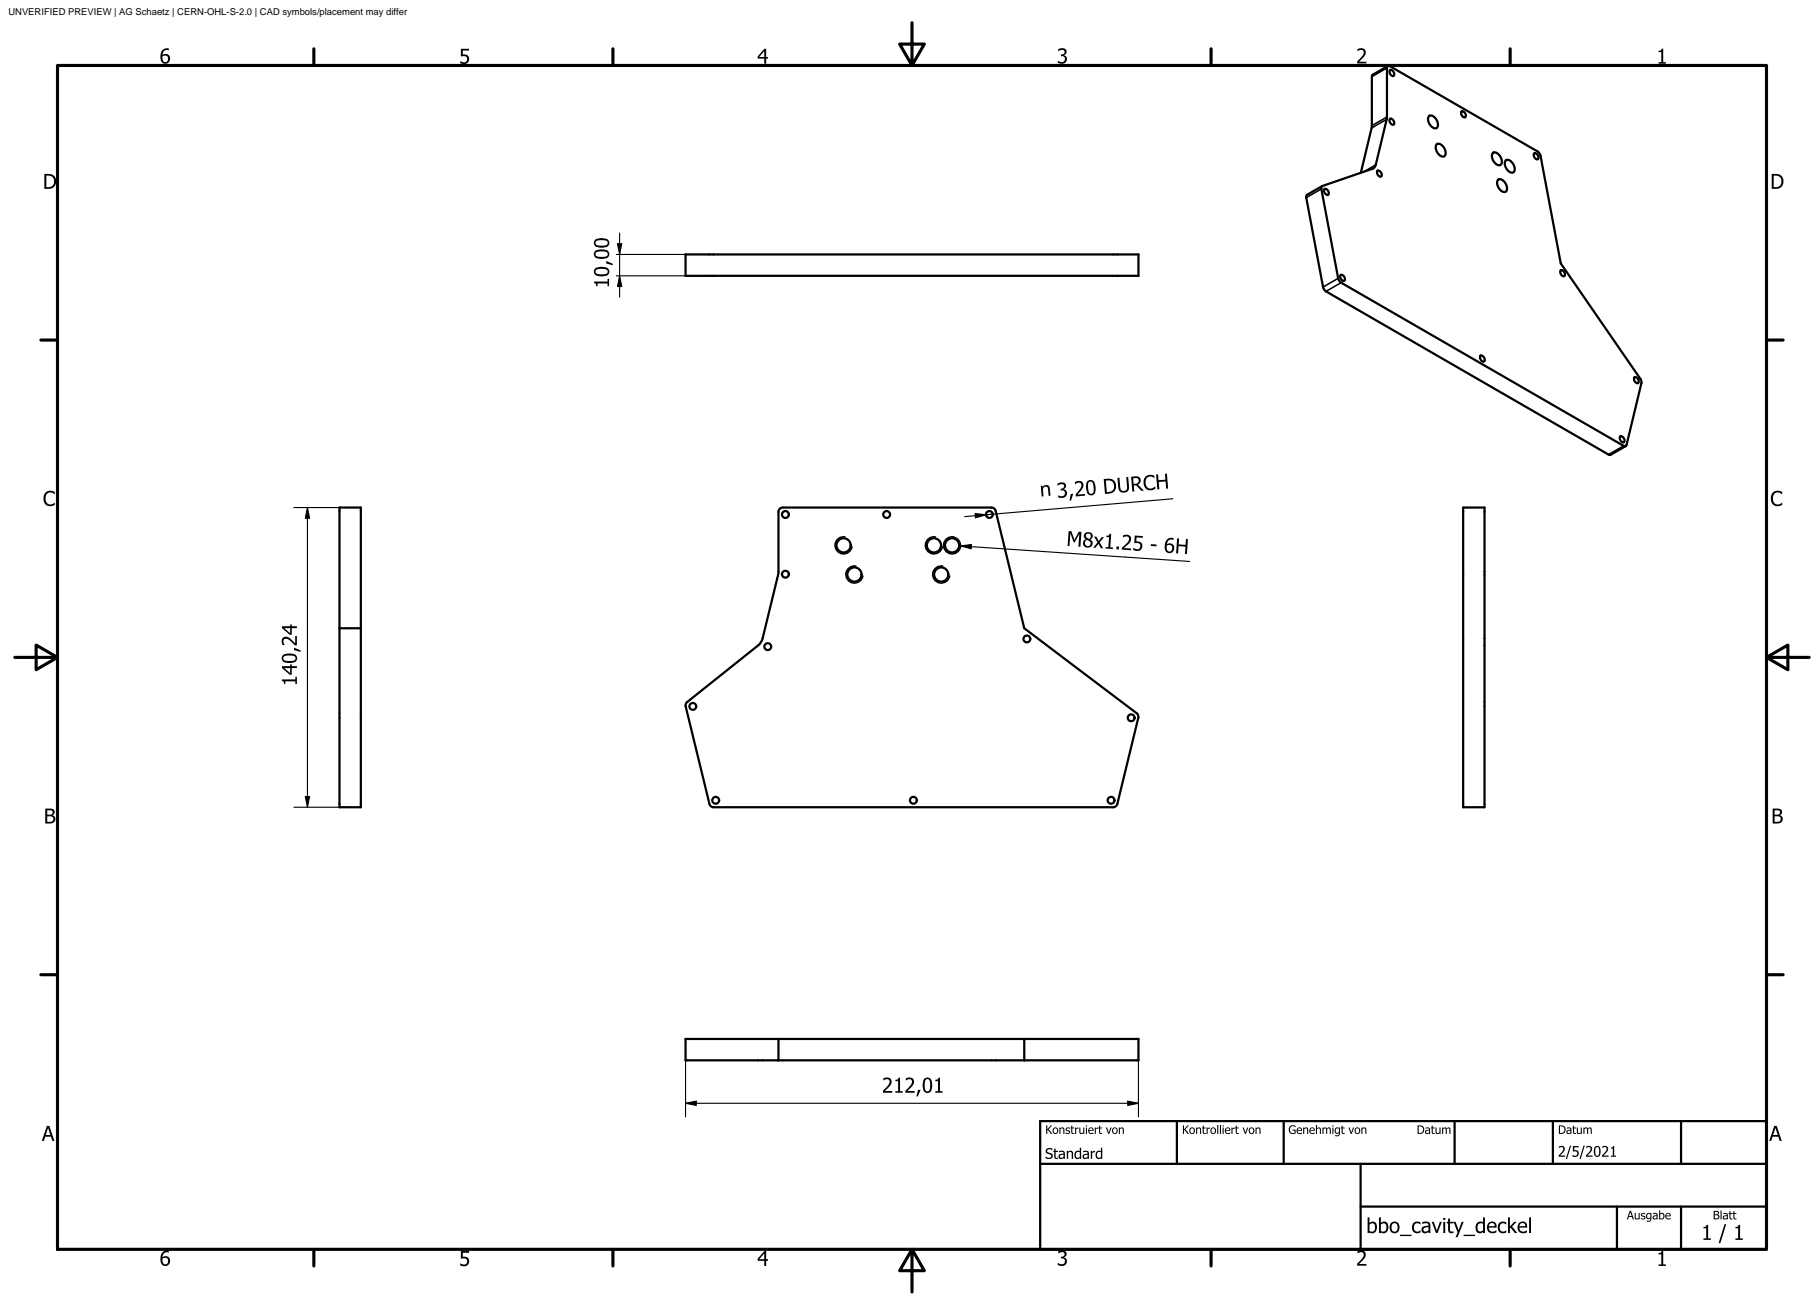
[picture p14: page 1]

UNVERIFIED PREVIEW | AG Schaetz | CERN-OHL-S-2.0 | CAD symbols/placement may differ

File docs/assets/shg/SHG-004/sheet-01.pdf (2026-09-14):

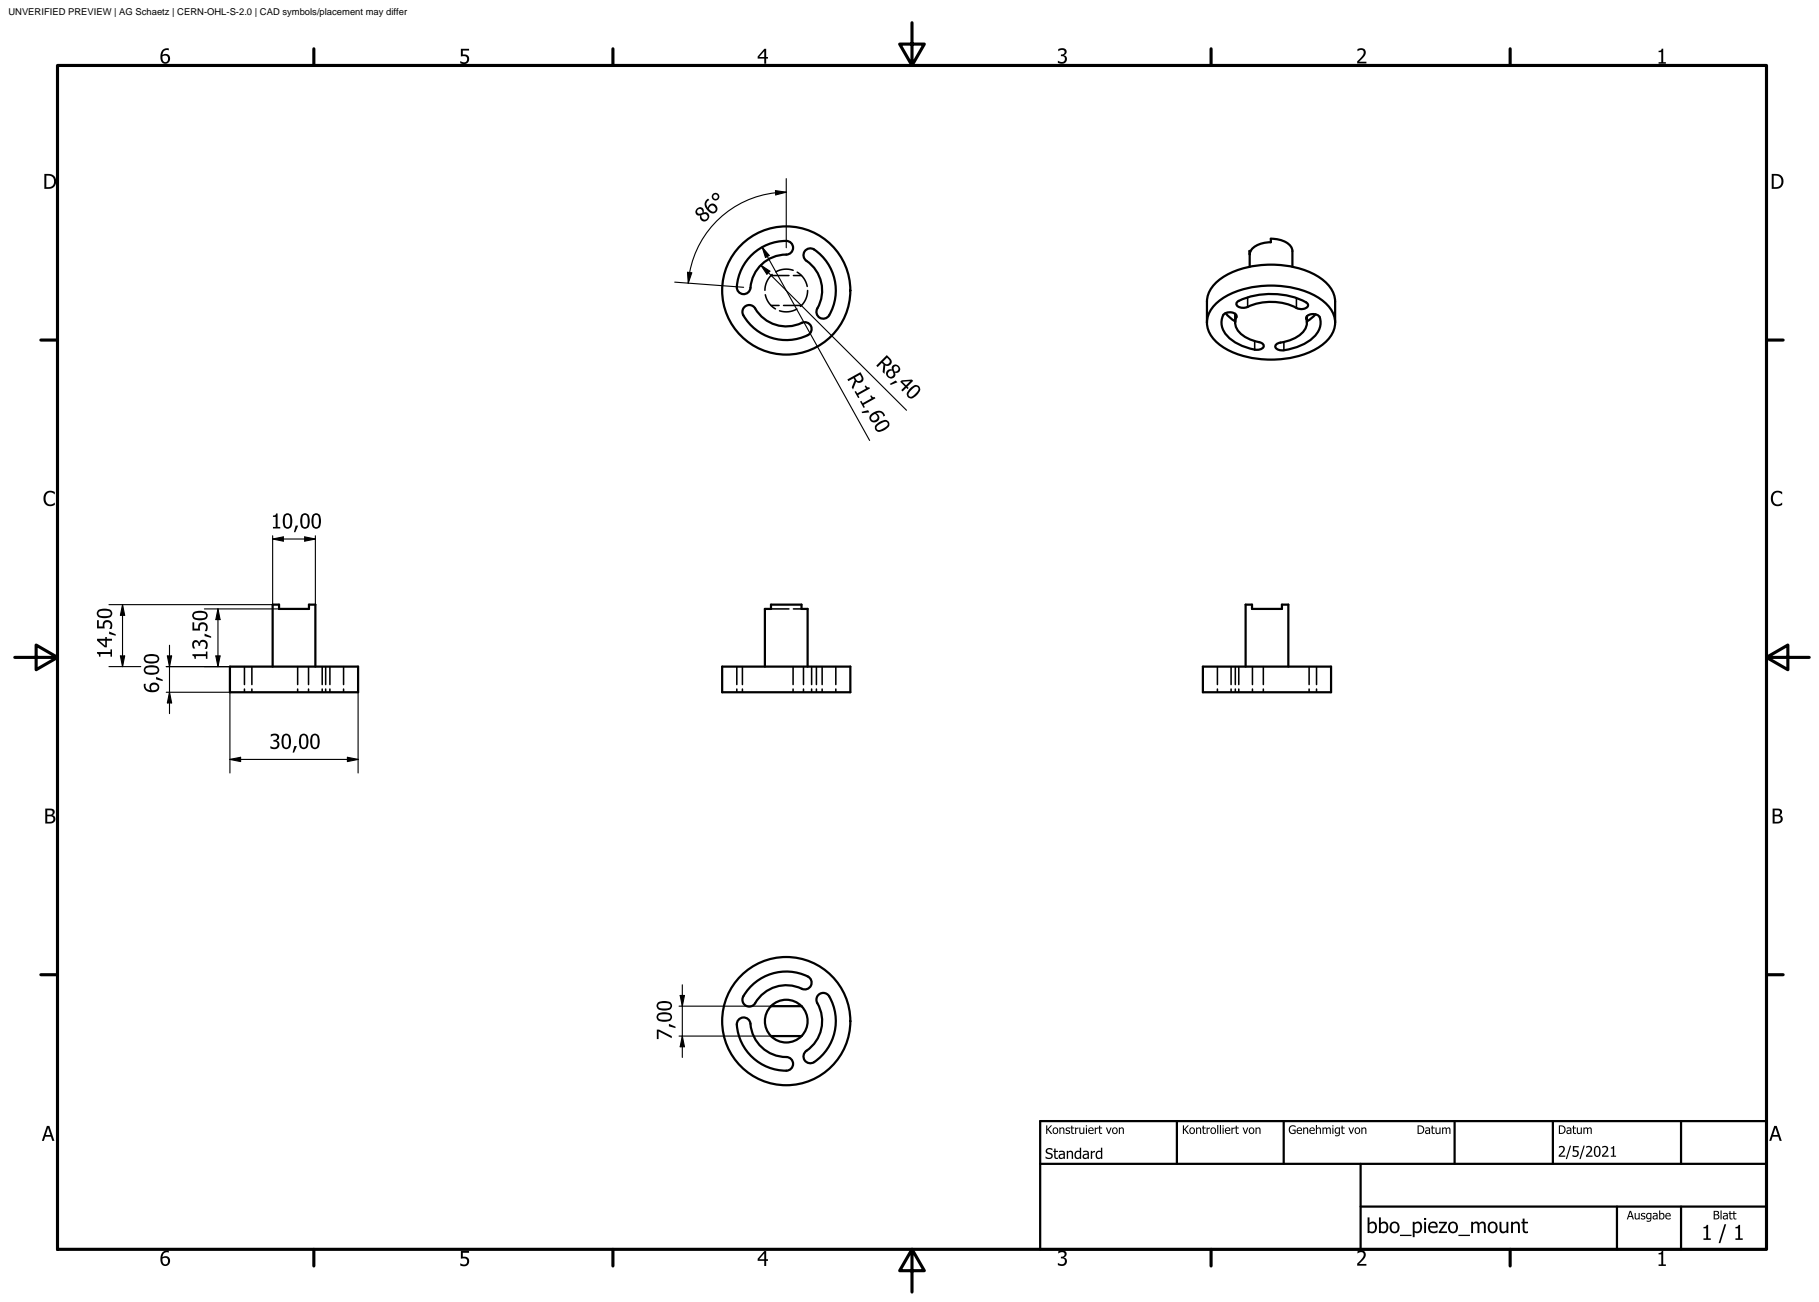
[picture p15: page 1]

UNVERIFIED PREVIEW | AG Schaetz | CERN-OHL-S-2.0 | CAD symbols/placement may differ

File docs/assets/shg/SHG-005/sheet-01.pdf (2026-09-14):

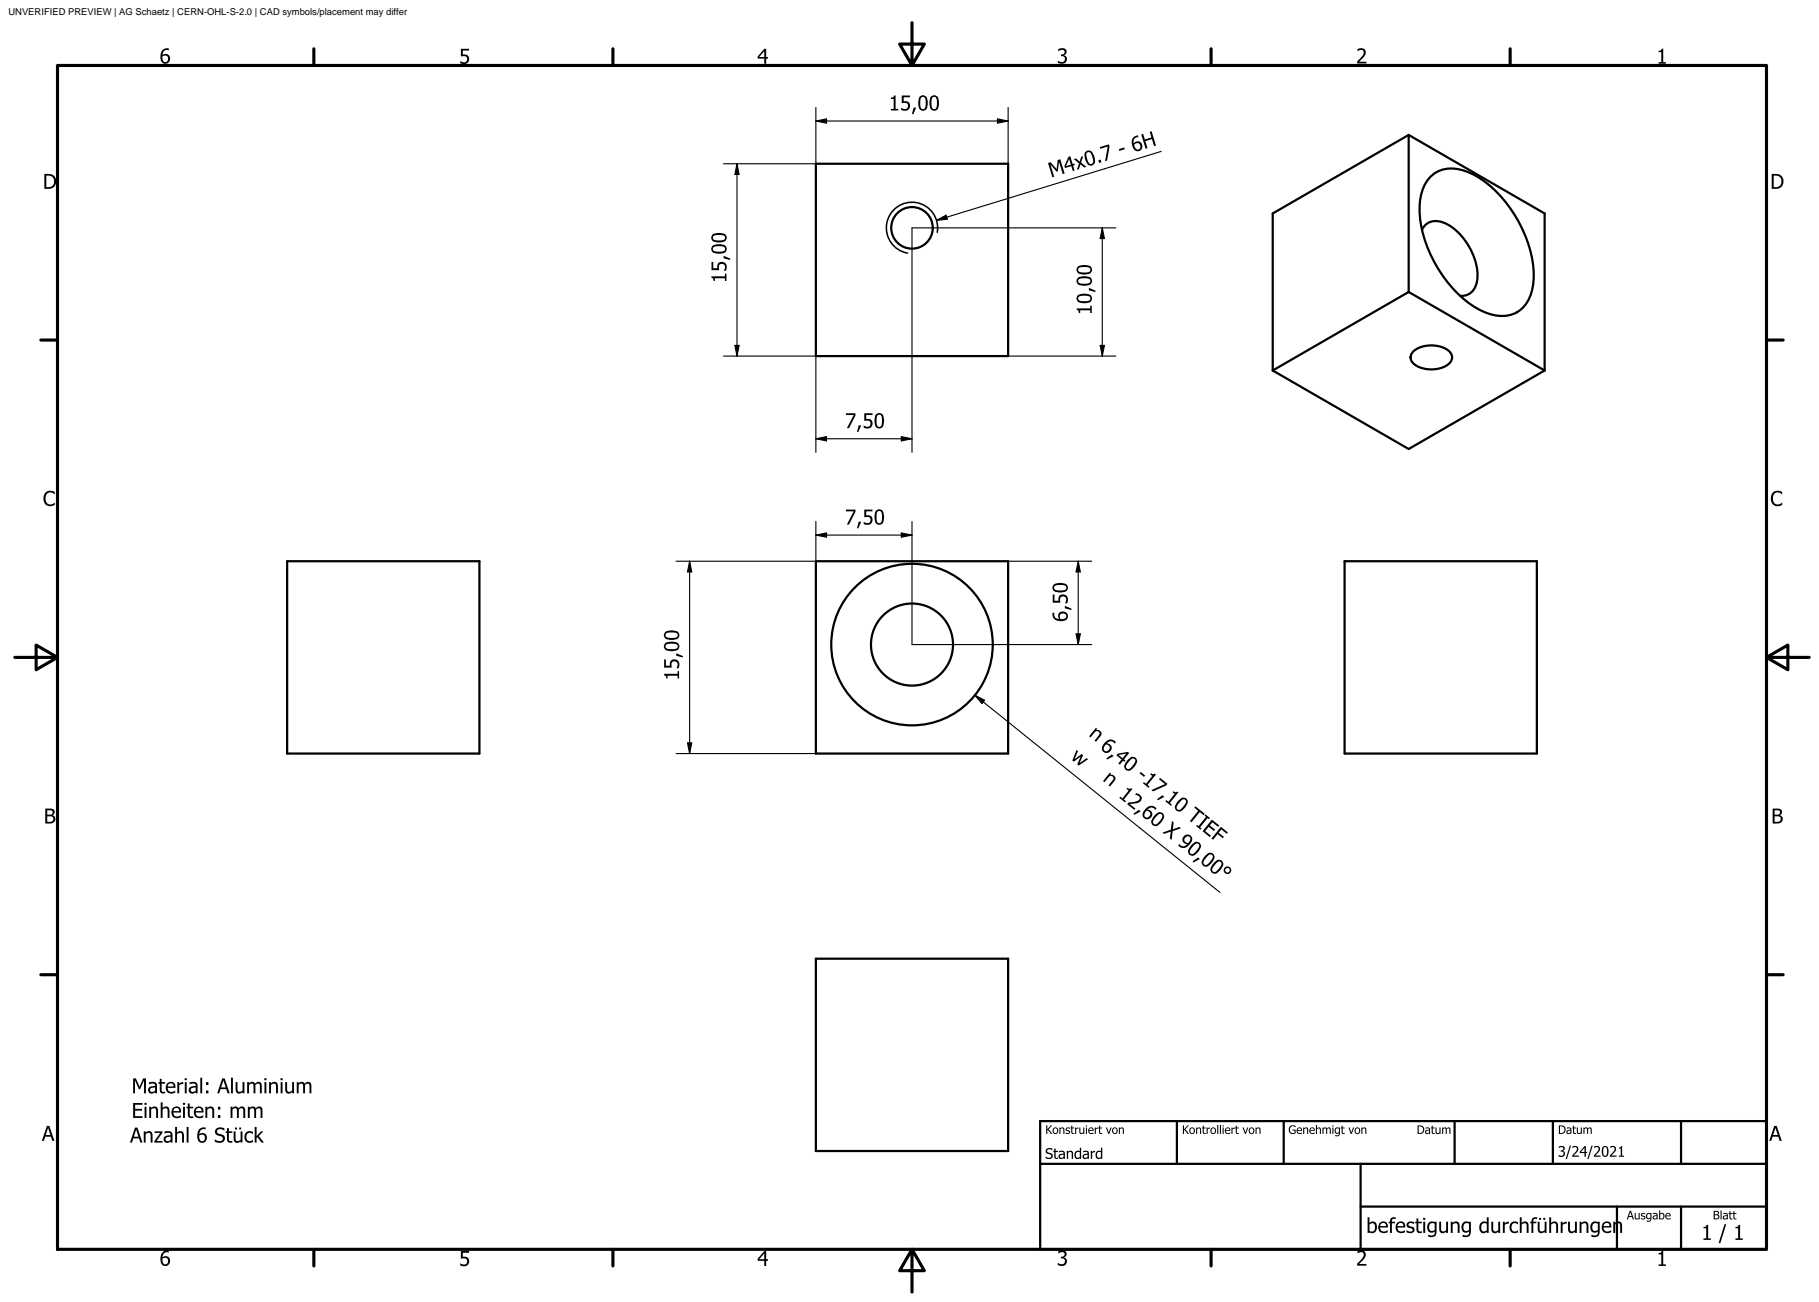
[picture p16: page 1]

UNVERIFIED PREVIEW | AG Schaetz | CERN-OHL-S-2.0 | CAD symbols/placement may differ

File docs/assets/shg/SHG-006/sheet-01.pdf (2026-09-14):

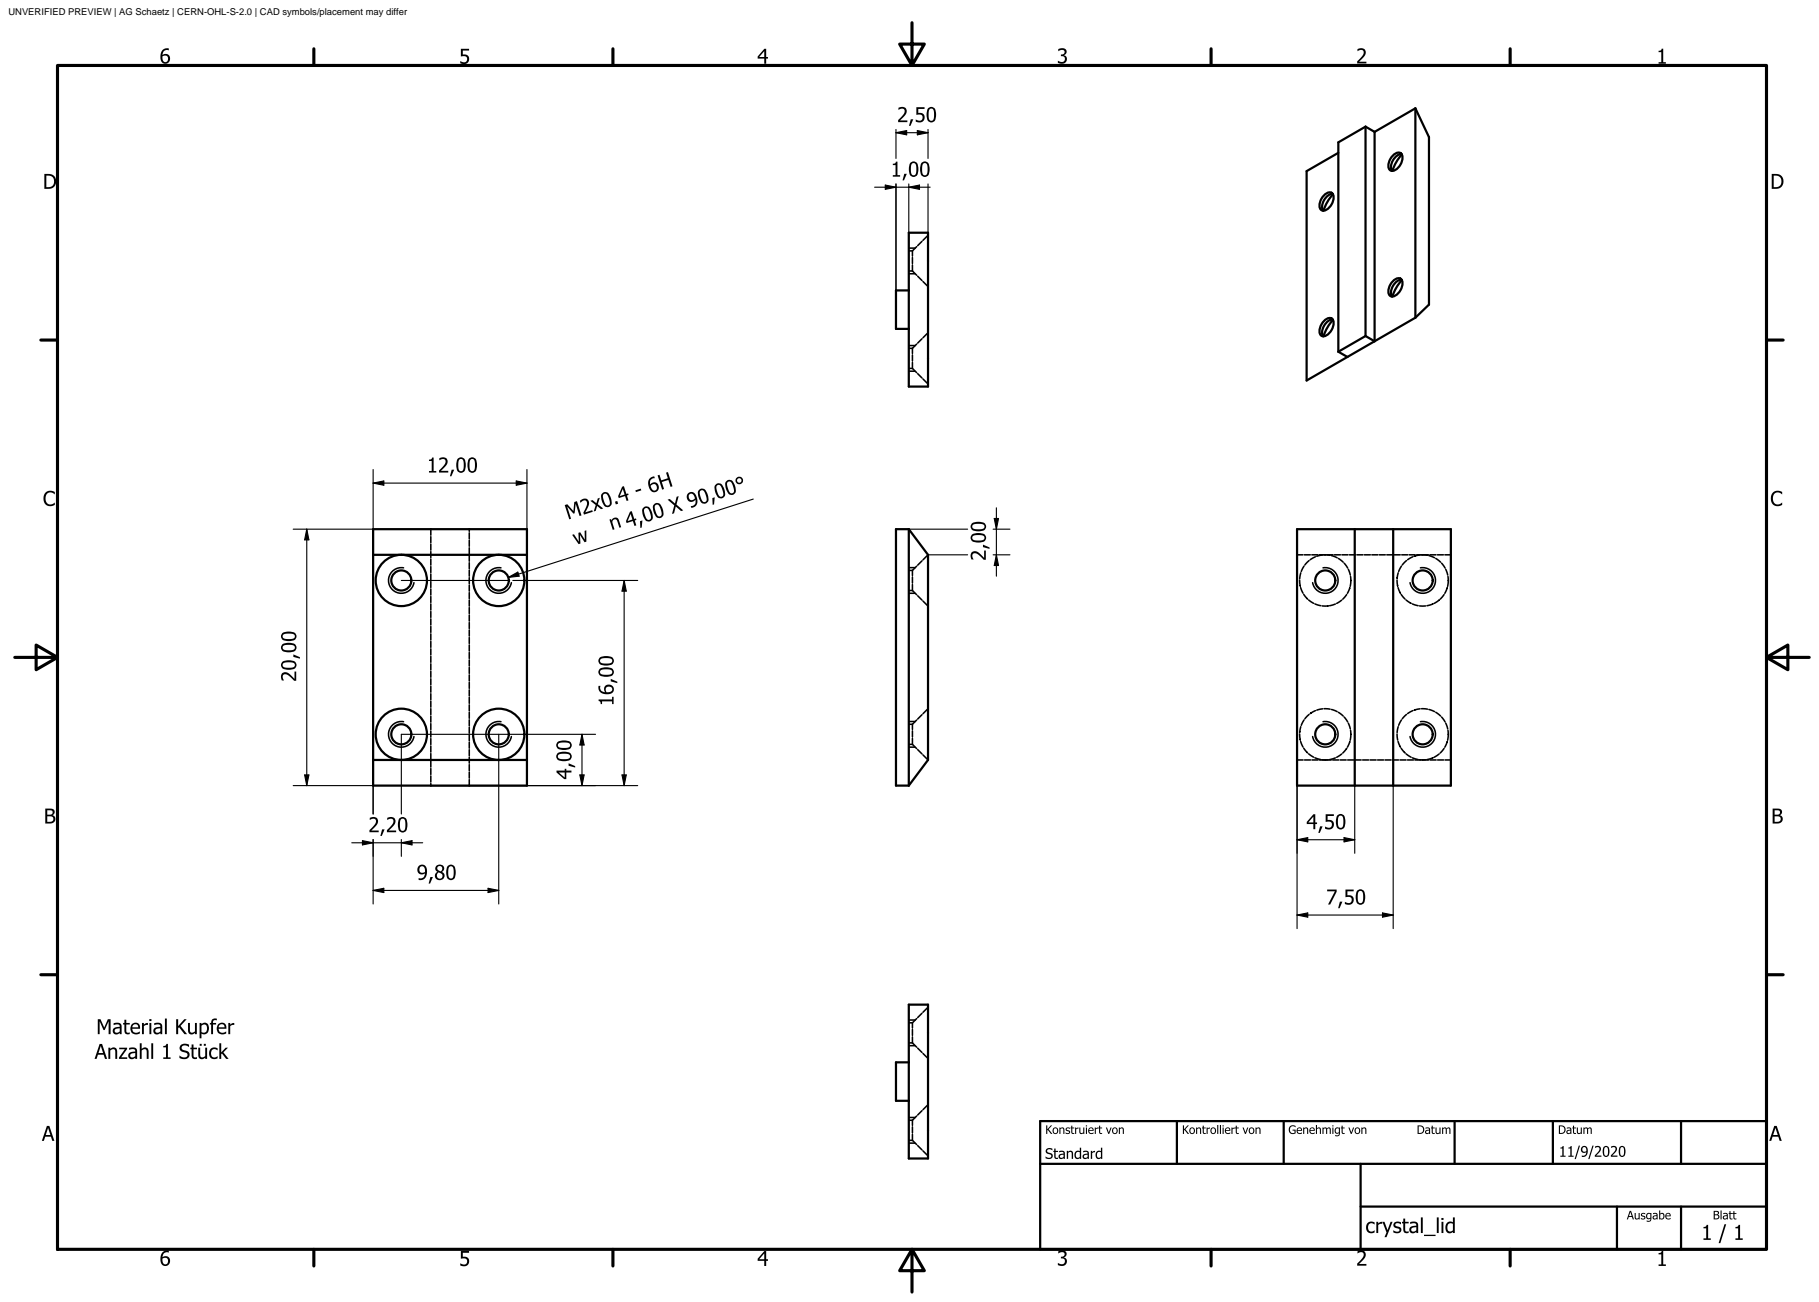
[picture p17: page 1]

UNVERIFIED PREVIEW | AG Schaetz | CERN-OHL-S-2.0 | CAD symbols/placement may differ

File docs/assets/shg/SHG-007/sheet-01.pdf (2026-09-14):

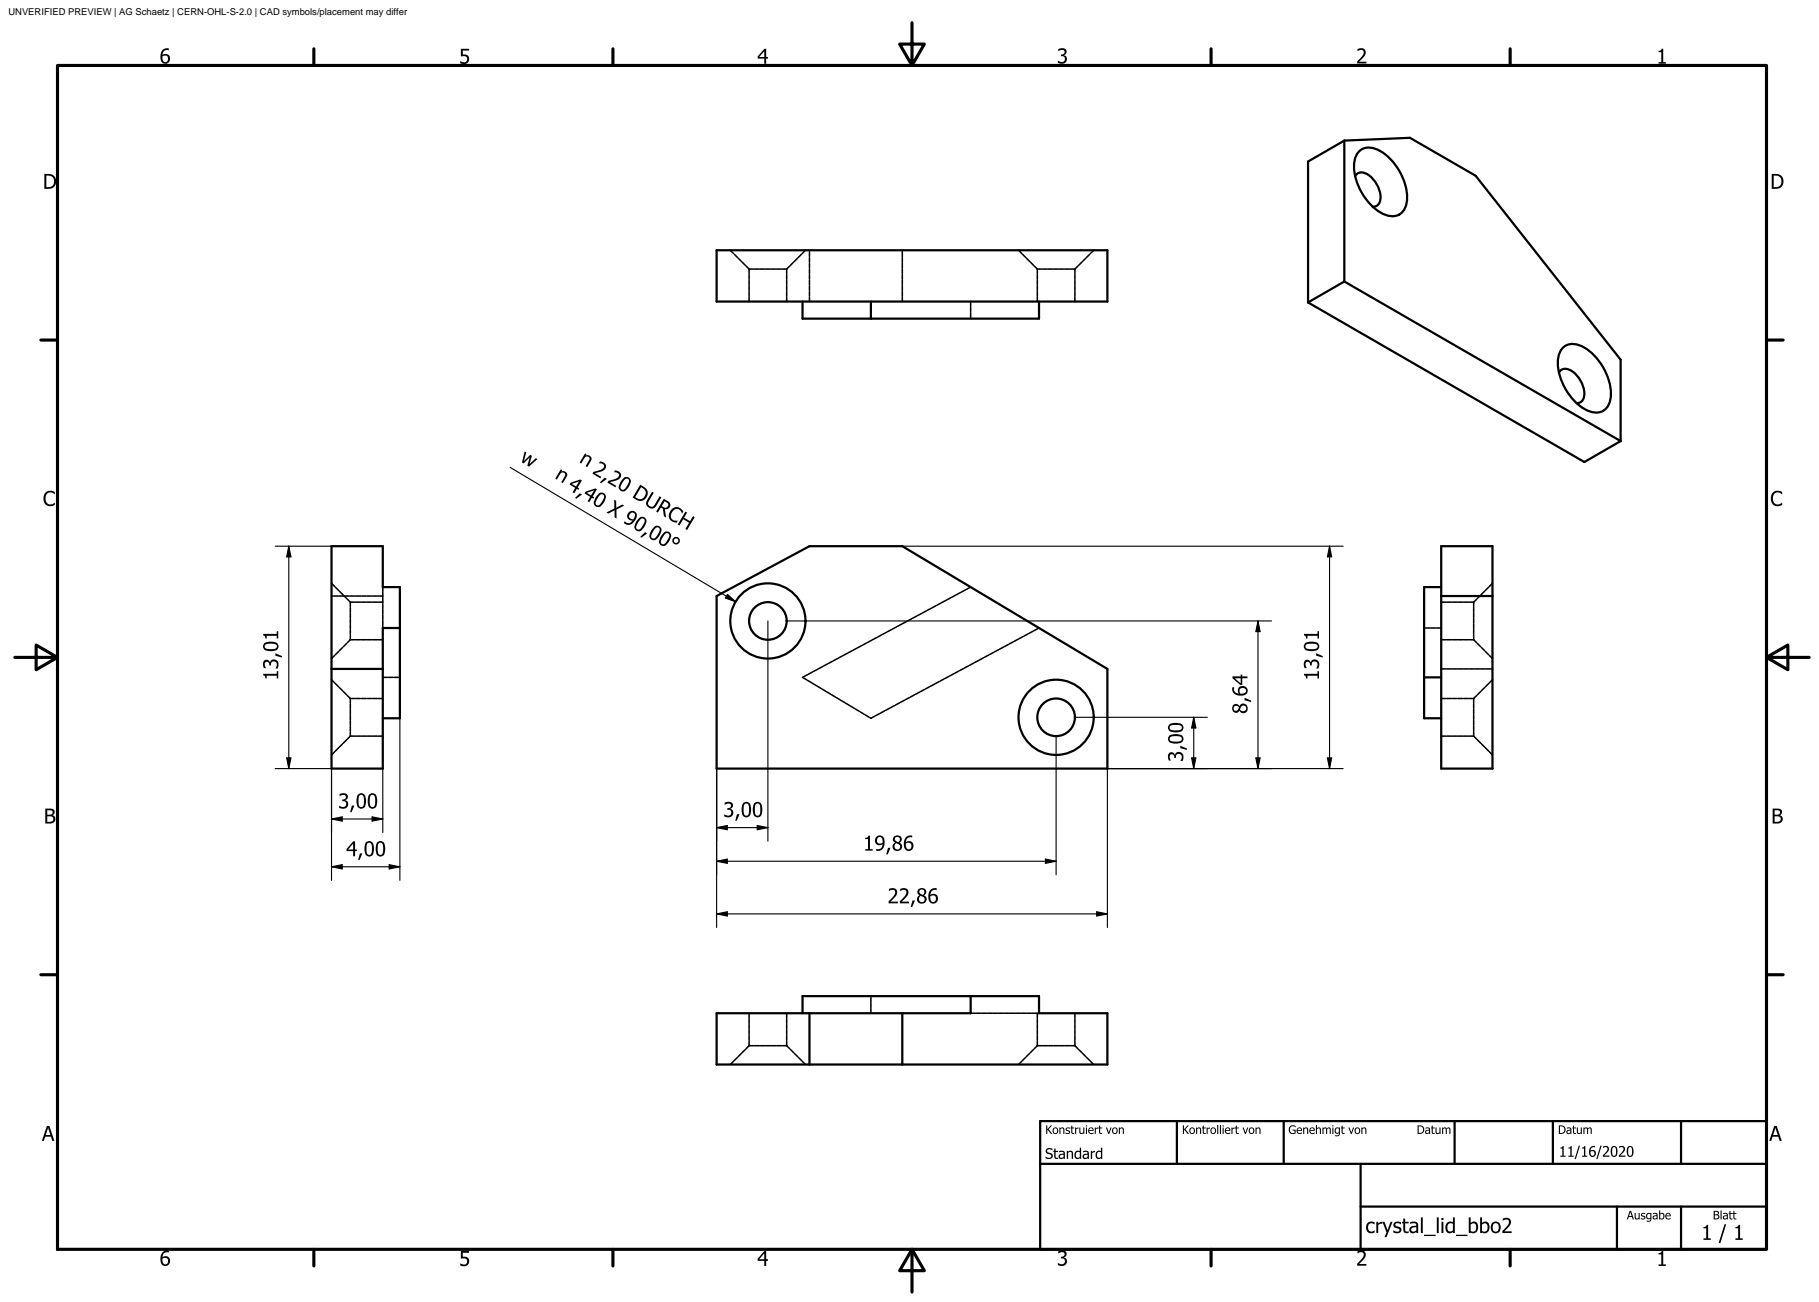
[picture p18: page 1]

UNVERIFIED PREVIEW | AG Schaetz | CERN-OHL-S-2.0 | CAD symbols/placement may differ

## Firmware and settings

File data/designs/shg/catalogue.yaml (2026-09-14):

schema_version: 1.0.0
collection_id: ag-schaetz-shg-2020-2021
author: AG Schaetz
publication:
  authorized_by: Ulrich Warring
  authorized_on: '2026-09-14'
  status: authorized
  licence_mapping: adopted explicitly by Steward on 2026-09-14
  decision_record: logbook/2026-09-14-shg-design-publication.md
licences:
  hardware: CERN-OHL-S-2.0
  metadata: CC-BY-4.0
  narrative: CC-BY-SA-4.0
  tooling: MIT
source_location: https://github.com/uwarring82/mg-plus-uv-chain/tree/main/data/designs/shg
evidence_tags:
  D: Directly extracted drawing value; not a hardware measurement
  D*: Ambiguous or inferred drawing interpretation
  OPEN: Not determined
designs:
- id: SHG-001
  original_filename: baseplate.dwg
  title_de: Grundplatte
  title_en: Baseplate
  title_basis: Curated filename translation; not an authorship or revision assertion
  stage: shared
  stage_basis: Filename/context; provisional
  kind: part
  classification:
    status: manual_drawing_review
    reviewed_on: '2026-09-14'
    basis: Orthographic/detail views describe one manufactured component
    evidence_tag: D*
    limitation: Based on cached drawing content; native assembly dependency graph unverified
  hardware_association:
    status: design_only
    evidence: []
    bench_evidence: []
  thesis_correspondence:
    status: not_established
    reference: Guth2021
    geometry_extraction: data/literature/Guth2021/geometry.yaml
  materials:
    value: null
    evidence_tag: OPEN
  tolerances:
    value: null
    evidence_tag: OPEN
  dimensions:
  - quantity: overall_length
    value_si: 0.615
    unit_si: m
    source_text: 615,00
    source_handle: '407'
    source_layout: Blatt
    evidence_tag: D
    basis: Transcribed dimension label; geometric measurement not independently checked
  - quantity: overall_width
    value_si: 0.44
    unit_si: m
    source_text: 440,00
    source_handle: 3E1
    source_layout: Blatt
    evidence_tag: D
    basis: Transcribed dimension label; geometric measurement not independently checked
  - quantity: thickness
    value_si: 0.02
    unit_si: m
    source_text: 20,00
    source_handle: 3F3
    source_layout: Blatt
    evidence_tag: D
    basis: Transcribed dimension label; geometric measurement not independently checked
  source:
    path: data/designs/shg/raw/SHG-001.dwg
    sha256: ae2d6676d5622bacbe4d32cdda36a766c859c7616f40cbed55f1613050c77144
    bytes: 386770
    dwg_header: AC1032
    archive_entry: SHG/baseplate.dwg
    archive_name_bytes_hex: 5348472f62617365706c6174652e647767
    zip_utf8_flag: false
    zip_modified_local: '2021-02-10T13:13:14'
    timestamp_timezone: unspecified
    original_filename: baseplate.dwg
  dxf:
    path: data/designs/shg/processed/SHG-001/SHG-001.dxf.gz
    sha256: 379d2ec1e09c21118cbdf2f6c90ddc6e94cc9cee8c8bbd8da6fe2181acbc98fa
    bytes: 363433
    uncompressed_sha256: 0fcd0fcca958c9806ac6104a8ce596a3ac41cee5ad12f5ba55faedecbde6a7c0
    uncompressed_bytes: 1225127
    content_type: application/gzip
    format: ASCII DXF AC1032 (gzip compressed)
  units:
    insunits_code: 4
    native: mm
    metres_per_unit: 0.001
    evidence: DXF $INSUNITS and independent source-reader INSUNITS
    source_reader_code: 4
  previews:
  - id: sheet-01
    name: Blatt
    qualifies: true
    reason: renderable_paper_content_or_reconstructed_cached_view
    fidelity: unverified
    svg:
      path: docs/assets/shg/SHG-001/sheet-01.svg
      sha256: 9278282b8a8cf475382c259042bb4a2f5cfbfe118975f628d218103117bdfe3b
      bytes: 289529
    pdf:
      path: docs/assets/shg/SHG-001/sheet-01.pdf
      sha256: 636a317e40dbef87b9385034a1d75c926460956c85bf133abde05fd501bff720
      bytes: 188713
    png:
      path: docs/assets/shg/SHG-001/sheet-01.png
      sha256: 055a330b382953dfae7398f5a93db33374fe1738b2ada16a2f06fd33ec8ab526
      bytes: 156318
    paper_size_native:
    - 420.0
    - 297.0
  inspection:
    path: data/designs/shg/processed/SHG-001/inspection.json
    sha256: 91e9fa20d76922b2db0455f3545e1f0c8e7f7bd8d9ea3d91b46ead49dcb3f9c6
    bytes: 26311
  source_inspection:
    path: data/designs/shg/processed/SHG-001/source-inspection.json
    sha256: 9457002fa3690b08265d644e3d66e379c89a26bd652a8307233e77705a6f8163
    bytes: 3179
  source_json:
    path: data/designs/shg/processed/SHG-001/SHG-001.dwg.json.gz
    sha256: e02656d4cbb7e85e14069c471f66668c416cc1cc9c05f13143368e5bd2f0393e
    bytes: 410512
    uncompressed_bytes: 3075303
    uncompressed_sha256: 64490bb9b087b4f54fbac6b852df919fa6dfeefcf16bc37796c56756f995d4e7
    licence: CERN-OHL-S-2.0
    format: LibreDWG JSON object graph (gzip compressed)
    interpretation: Unknown proxy payloads remain opaque
  conversion_observations: []
- id: SHG-002
  original_filename: bbo_cavity.dwg
  title_de: BBO-Resonator
  title_en: BBO cavity
  title_basis: Curated filename translation; not an authorship or revision assertion
  stage: BBO
  stage_basis: Filename/context; provisional
  kind: part
  classification:
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

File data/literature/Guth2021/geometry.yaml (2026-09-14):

citation_key: Guth2021
section: 2.2.2 Geometry of Cavities
extracted_on: '2026-09-14'
extracted_by: assistant under Ulrich Warring direction
status: DRAFT; printed values visually checked, hardware association unconfirmed
source:
  path: data/literature/Guth2021/Guth2021.pdf
  sha256: ec2ce3be941b289309998a1260d9466ca7300d2f3869087c7cf50d2e718aee1f
  committed: false
  printed_pages:
  - 25
  - 26
  - 27
  - 28
  - 29
  - 30
  pdf_pages_one_based:
  - 30
  - 31
  - 32
  - 33
  - 34
  - 35
method: pdftotext -layout plus visual review of all six relevant rendered pages
evidence_tags:
  T: Directly transcribed thesis table value; not a hardware measurement
  OPEN: Not determined from the inspected section
association_limit: Thesis correspondence may support provisional association only; confirmed hardware
  requires bench evidence. Figures 12 and 14 are attributed to reference [44].
parameters:
- symbol: LBO_crystal_length
  value: 0.018
  units: m
  source_value_text: 18 mm
  location: Table 3; Eq. 21
  printed_page: 30
  pdf_page_one_based: 35
  evidence_tag: T
  notes: Direct printed design parameter.
- symbol: LBO_M1_M2_spacing
  value: 0.136
  units: m
  source_value_text: 13.6 cm
  location: Table 3; Fig. 13 caption
  printed_page: 30
  pdf_page_one_based: 35
  evidence_tag: T
  notes: Planar mirror separation l3.
- symbol: LBO_M3_M4_spacing
  value: 0.064
  units: m
  source_value_text: 6.4 cm
  location: Table 3; Fig. 13 caption
  printed_page: 30
  pdf_page_one_based: 35
  evidence_tag: T
  notes: Curved mirror separation l2.
- symbol: LBO_cavity_length
  value: 0.4
  units: m
  source_value_text: 400 mm
  location: Table 3
  printed_page: 30
  pdf_page_one_based: 35
  evidence_tag: T
  notes: Reported cavity length, not a bench measurement here.
- symbol: LBO_M3_curvature_printed
  value: 0.5
  units: m
  source_value_text: 50 cm
  location: Table 3
  printed_page: 30
  pdf_page_one_based: 35
  evidence_tag: T
  notes: 'Potential unit error: preserve as printed; do not substitute 50 mm without evidence.'
- symbol: LBO_M4_curvature_printed
  value: 0.5
  units: m
  source_value_text: 50 cm
  location: Table 3
  printed_page: 30
  pdf_page_one_based: 35
  evidence_tag: T
  notes: 'Potential unit error: preserve as printed; do not substitute 50 mm without evidence.'
- symbol: BBO_crystal_length
  value: 0.01
  units: m
  source_value_text: 10 mm
  location: Table 3; paragraph above Summary
  printed_page: 30
  pdf_page_one_based: 35
  evidence_tag: T
  notes: The paragraph attributes the detailed calculation to reference [44].
- symbol: BBO_cavity_length
  value: 0.47
  units: m
  source_value_text: 470 mm
  location: Table 3; paragraph above Summary
  printed_page: 30
  pdf_page_one_based: 35
  evidence_tag: T
  notes: The paragraph attributes the detailed calculation to reference [44].
- symbol: BBO_M3_curvature
  value: 0.05
  units: m
  source_value_text: 50 mm
  location: Table 3
  printed_page: 30
  pdf_page_one_based: 35
  evidence_tag: T
  notes: Direct printed value.
- symbol: BBO_M4_curvature
  value: 0.05
  units: m
  source_value_text: 50 mm
  location: Table 3
  printed_page: 30
  pdf_page_one_based: 35
  evidence_tag: T
  notes: Direct printed value.
- symbol: BBO_curved_mirror_to_crystal
  value: 0.0246
  units: m
  source_value_text: 24.6 mm
  location: Table 3
  printed_page: 30
  pdf_page_one_based: 35
  evidence_tag: T
  notes: Label does not resolve crystal face versus center; no derived mirror separation asserted.
open_items:
- symbol: LBO_fold_angle
  value: null
  evidence_tag: OPEN
  notes: Text says incidence angles below 15 degrees on p25; no exact fold angle extracted.
- symbol: BBO_fold_angle
  value: null
  evidence_tag: OPEN
  notes: No exact numerical fold angle in the inspected section; do not import the Friedenauer value
    as a Guth-stated value.
- symbol: crystal_absolute_position
  value: null
  evidence_tag: OPEN
  notes: Figure 12 and Eq.25 place LBO centrally between curved mirrors; no absolute CAD coordinate
    is established.

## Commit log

2026-04-30 Initial commit: Charter v1.0 frozen, Phase 0 complete
    Establishes the repository skeleton for the ²⁵Mg⁺ UV chain redesign:
    Charter (frozen v1.0), conventions, citation metadata, dual licensing
    (MIT for code, CC-BY-4.0 for documents), Level 0/1 constraint objects,
    SI-units parameter contract, kickoff logbook with deliberation history,
    and gate-closure template per CHARTER §5.3.
2026-05-01 feat(infra): add architecture-neutral simulation utilities, build, tests
    Adds the pre-G1 infrastructure layer permitted by CHARTER §5.1
    (architecture-neutral shared infrastructure):
    - pyproject.toml: setuptools build, Python ≥ 3.11, deps pinned
    (numpy, scipy, matplotlib, pyyaml). Test/dev extras. Co-located
    configs for pytest, coverage (fail_under = 90 per Phase 3 row),
    black, isort, ruff, mypy. Coverage omits the diagnostic-surrogate
    archive subtree per §5.1.
    - src/boyd_kleinman.py: generic SHG focusing function h(σ, β, κ, ξ, μ)
    via dblquad, σ-optimised h_m, h_m_optimum finder, and the closed-form
    arctan²(ξ)/ξ analytic limit for unit-test reference. No architecture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
2026-05-01 gate(governance): file Phase 0.5 G3 candidate values; Phase 4 still blocked
    Files candidate values for the Phase 0.5 reference triple
    {Δ_ref, Ω_R,ref, Γ_sc,ref} and the Conservative / Nominal / Aggressive
    bounded-scenario set per CHARTER §1.5 stall mitigation. Phase 4
    architecture comparison is NOT unblocked by this commit; it remains
    blocked behind G3_INTEGRATOR_ACKNOWLEDGED until the §5.3 gate-closure
    protocol records Integrator confirmation.
    src/parameters.py:
    - Adds G3_INTEGRATOR_ACKNOWLEDGED = False as the binding gate flag.
    - Populates DELTA_REF_Hz, OMEGA_R_REF_Hz, GAMMA_SC_REF_per_s with
    Nominal scenario candidate values (40 GHz, 400 kHz, 2.0e4 s⁻¹).
    - Populates Conservativ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
2026-05-01 docs(literature): scaffold Phase 1 KD-2026-XXX-uv-280nm.md dossier
    Adds the Phase 1 literature dossier scaffold per CHARTER §5 Phase 1
    row. Format follows the Kompass-Dossier pattern (Section A claim /
    Section B predictions / Section C constraints) with §8 outcome
    classification (Resolved / Operationally bounded / Underdetermined),
    mirroring the moonshots/luna/DOSSIER.md structure adapted to
    technical literature scope.
    Contents:
    - Endorsement marker, scope, source-tier convention ([P]/[S]/[I]).
    - 15 ledger entries spanning the four CHARTER §4 architecture
    families (KD-UV280-001 to -004), the §5 Phase 1 crystal/coating
    evidence demands (BBO, CLBO, LBO, UV coatings, hygroscopic
    cons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
2026-05-01 docs(literature): populate KD-UV280-013 from Friedenauer 2006 (Resolved/DRAFT)
    Populates the Friedenauer 2006 baseline-extraction entry from a direct
    read of the published paper (PDF, local user library; not committed).
    Closes the entry as Resolved / DRAFT in the dossier index pending
    Steward review against the source.
    data/literature/Friedenauer2006/extracted.yaml (new):
    - 57 structured parameters per the data/README.md schema, covering
    source chain (1118 nm Yb fibre, ASE, isolator, polarization handling),
    LBO first-stage SHG (crystal type/length/temperature, Boyd-Kleinman
    optimum waist, ring-cavity geometry, mirror reflectivities,
    conversion efficiency), BBO second-stage SHG (Brew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
2026-05-01 gate(governance): close G3 — Integrator-acknowledged; Phase 4 unblocked
    Closes the Phase 0.5 G3 gate per CHARTER §5.1 and §5.3, recording
    Integrator acknowledgement and the closure-commit attestations.
    Single-steward stance attribution: Ulrich Warring acts as the
    Integrator stance per the pattern established in CHARTER §12 v1.0
    sign-off block. Architect and Guardian flags: not raised.
    - G3_INTEGRATOR_ACKNOWLEDGED = True (was False at filing).
    - Comment block updated to reflect post-closure state and the §9
    asymmetric erosion protection that now applies (tightening
    permitted with rationale; relaxation requires Council-3 + Integrator).
    - Locked values: Δ_ref = 4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
2026-05-01 docs(governance): update README — G3 closed; Phase 1 dossier 5/15 populated
    Brings README.md in sync with the post-G3-closure repository state.
    - Status line: replaces "Phase 0 complete; Phase 0.5 begins next" with
    the current state — Charter v1.0 frozen, G3 closed 2026-05-01,
    Phase 1 dossier at 5/15 entries past SCAFFOLD, Phase 2 / Phase 4
    unblocked from G3 forward, G1 and G2 still OPEN.
    - Kill-gate table: G3 row updated to CLOSED with link to the closure
    logbook entry. G1 and G2 rows unchanged.
    No file substance touched beyond status reporting; CHARTER.md itself
    is unchanged (per the v1.0 freeze).
    Affects-Level-0: no
    Affects-Level-1: no
    Affects-Success-Criteria: no
    Co-Autho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
2026-05-01 chore(governance): tighten G3-vs-G2 wording; fix publication metadata
    Pre-public-push housekeeping in two parts.
    Governance wording — G3 closure does NOT override G2:
    - README.md status line and logbook/2026-05-01-gate-g3-closure.md
    closure-decision line previously read "Phase 4 architecture comparison
    unblocked" or "may commence" without distinguishing G3-blocking from
    the other Phase 4 entry conditions. A reader could conclude G3 closure
    overrides G2 by inheritance — it does not.
    - New wording in both files: "G3 no longer blocks Phase 4" with explicit
    enumeration of the remaining gates: G2 (degradation-rate inputs to
    axes 3/4 scoring) and the §5.1 G1 anti-seeding clause f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
2026-05-02 fix(simulation): bound h_m_optimum search; correct BK-recalc notebook narrative
    Six related fixes flagged in the post-92f6f43 review.
    src/boyd_kleinman.py — load-bearing bug fix
    - h_m_optimum() previously used scipy minimize_scalar with method='brent'
    and an `xi_bracket` that Brent could (and did) extrapolate outside,
    asking h_factor to evaluate at negative ξ. h_factor's xi > 0 guard
    then raised ValueError, breaking any downstream caller (e.g. the
    Friedenauer BBO walk-off calculation in the notebook).
    - Switched to method='bounded' with strict `xi_bounds` (renamed from
    the misleading `xi_bracket`). Default bounds (0.05, 10.0) cover the
    tested regime; callers can override.
    - A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
2026-05-02 chore(governance): add Steward ORCID; resolves last pre-push BLOCKING marker
    CITATION.cff line 17: replaces the commented-out placeholder ORCID and
    its `BLOCKING: Steward to insert before first public push` marker with
    the real Steward ORCID 0000-0001-8081-9718.
    Verified: CITATION.cff parses cleanly with the standard YAML loader
    and the ORCID field is correctly attributed to the single author entry
    (Ulrich Warring, Albert-Ludwigs-Universität Freiburg, AG Schätz).
    No other BLOCKING or TODO markers remain in CITATION.cff or
    pyproject.toml. The repository is now eligible for first public push
    under the FAIR commitments declared in CHARTER §7.
    Affect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
2026-05-06 docs(literature): populate Task E literature inventory
    Three DRAFT extractions from user-provided PDFs (peer-reviewed [P]):
    - Kondo1998 (Opt. Lett. 23, 195-197): >1000 h CW 266 nm BBO
    reliability, 100 mW, w0 = 46 um, empirical degradation rate vs UV
    power density, RIN < -130 dB/Hz, N2-purge / sealed-cavity protocol.
    Maps to KD-UV280-005, -009, -011.
    - Kubota1998 (OSA TOPS 17, paper FC4): companion proceedings paper
    with full Cz-BBO characterisation, CW + pulsed reliability, unified
    p(E) = C exp(-K/E) damage-probability model, thermal -> multiphoton
    transition argument, and the post-pulsed HeNe tomographic image
    showing UV-driven (not green-driven) defect formation. Maps to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
2026-05-06 docs(literature): promote Burkley2021, Brown2019, Kumar2015 to DRAFT
    Three coating / mechanism extractions for Task E. Source-tier
    [P] for all three; PDFs retained in the gitignored downloads area.
    - Burkley2021 (arXiv 2105.14977; folder renamed from
    vonMilczewski2021/ after PDF read corrected the scout-pass author
    guess): direct head-to-head test of fused-silica vs CaF2 input
    couplers in a 244 nm CW enhancement cavity. Fluoride stable up to
    10 W in UHV after UV-conditioning, up to 20 W from 10^-4 to 1 mbar
    O2 for multi-hour timescales. Oxide degrades rapidly below ~0.67
    mbar O2 (Cooper 2018 prior-art baseline). Mechanism distinguished
    as hydrocarbon contamination, not surface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
2026-05-06 docs: promote four Mg+ application papers to DRAFT; populate Section C
    Four DRAFT extractions completing the Task E literature inventory:
    - Hemmerling2011 (Appl. Phys. B 104, 583): PTB Braunschweig 25Mg+
    ground-state cooling, 1118.21 nm Yb-fibre + LBO + BBO chain at
    60 mW UV. Key Task-E observation: explicit CW UV-induced surface
    damage on UV-grade fused-silica AOM / mirror / prism surfaces at
    32-64 W/cm^2 over a few hours, with re-design mitigation. The only
    280 nm-specific CW UV surface-damage threshold available -- adjacent
    wavelength caveat does not apply. Author-list correction logged
    (U. Warring is NOT on this paper, contrary to scout-pass guess).
    - Kjaergaard2000 (Appl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
2026-05-07 docs(workplan): numerics expansion plan v1.1 (peer-review revision)
    Two independent peer reviewers flagged blocking and medium issues in the
    v1.0 draft. Folded into v1.1:
    - Phase A API split: single_pass_efficiency() (W) replaced by
    single_pass_harmonic_power_W() (W) + single_pass_conversion_fraction()
    (dimensionless). The cavity solver consumes the fraction so the
    depleted regime is handled correctly.
    - Phase B optimal-IC scaling corrected: closed-form small-signal match
    T_opt = (L + sqrt(L^2 + 4*gamma*P_in))/2; high-pump leading order
    T_opt -> sqrt(gamma*P_in) with no L_passive under the radical.
    Exact intensity-form match T = 1-(1-L)(1-eta_nl) made explicit;
    the -L*eta_nl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
2026-05-07 feat(src): Phase A — single-pass SHG coefficient + anti-seeding test
    Implements the architecture-neutral bridge from Boyd-Kleinman h_m to
    the engineering coefficient gamma_SHG (W^-1):
    - boyd_kleinman_K_factor(d_eff, n_omega, n_2omega, wavelength_m)
    - gamma_shg_coefficient(..., h_m) — no walk-off arg; BK layer owns
    focusing geometry, SHG layer owns material/wavelength coupling.
    - single_pass_harmonic_power_W(power_in, gamma, regime)
    -> small-signal gamma*P^2 / depleted P*tanh^2(sqrt(gamma*P))
    - single_pass_conversion_fraction(power_in, gamma, regime)
    -> dimensionless eta in [0, 1]; the function the Phase B cavity
    solver consumes (not gamma*P^2, which silently fails depleted).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
2026-05-07 feat(src): Phase B — enhancement-cavity steady-state solver
    Implements the architecture-neutral SHG ring-cavity solver consuming
    single_pass_conversion_fraction from Phase A:
    - passive_buildup(T_IC, L) — closed-form Airy buildup; reaches 1/L at
    impedance match.
    - circulating_power(P_in, T_IC, L, gamma) — brentq over the cavity
    equation P_circ = P_in·T/(1 - sqrt(R(1-L)(1-eta_nl)))^2; uses
    regime="depleted" for eta_nl so the residual is C^1-continuous and
    the solver does not oscillate at the small/depleted threshold from
    the public Phase A "auto" default.
    - harmonic_output_W(...) — evaluates single_pass_harmonic_power_W at
    the converged P_circ; clamped at P_in (cavity-lev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
2026-05-07 docs(workplan): mark Phase B done; record solver refinements
    - Phase B heading marked DONE with commit 232e3d5 and 91 -> 119 test
    - Records four implementation refinements that were compatible with
    v1.1 but not anticipated in the original test plan:
    1. Adaptive T_high expansion for highly-depleted regimes.
    2. Cavity-level Manley-Rowe clamp on harmonic_output_W (guards
    ~1e-13 floating-point overshoot in the saturated regime).
    3. Saturated-regime graceful fallback (T_match -> 1 returns T_high
    rather than raising).
    4. Test tolerance on the linearised quadratic oracle calibrated to
    the leading-order depleted-tanh^2 correction (rel=1e-2 at
    gamma*P_circ~0.02;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
2026-05-07 feat(src): Phase C — SHG cascade composition over Phase A/B primitives
    Architecture-neutral helpers for composing two or more enhancement-cavity
    stages with inter-stage transport efficiencies. The LBO -> BBO chain is
    the canonical use case but no architecture, wavelength, or material
    preset appears in this module.
    - Stage(loss_per_pass, gamma_shg, T_IC) frozen dataclass — operating-
    point parameters of one cavity. Frozen so it's hashable and so the
    optimiser-returned objects can't be mutated by accident downstream.
    - cascade_output(P_in, stages, transport_efficiencies) — evaluates a
    cascade at fixed operating points. Returns a dict with per-stage
    details (input_W, circulating_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
2026-05-08 docs(literature): VECSEL seed-laser dossier + alphabetical references index
    Lands the 2026-05-08 steward direction (VECSEL as seed-laser source class
    for current and future builds of mg-plus-uv-chain) together with the
    in-house thesis chain that operationally underwrites it at 1118 nm, and
    adds a project-wide alphabetical references index with short citation
    labels.
    Steward-direction artefacts:
    - data/literature/Burd2023/ — [P] design-principles anchor (Burd et al.,
    JOSA B 40, 773 (2023)); class-A laser dynamics, intracavity BRF + YAG
    etalon + PZT mode-selection; <100 kHz linewidth at 940 nm.
    - docs/components/seed-lasers.md — components-page surface for the
    seed-laser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
2026-05-08 fix(architectures): correct IC-VECSEL visible-stage budget — needs ~ 500 mW visible to deliver 50 mW UV
    The earlier framing implied that the cooling-and-repumping-only task
    allocation (50 mW UV) relaxed the IC-VECSEL visible target to
    ~ 50-100 mW @ 559 nm, which would have been inside the [Burd16]
    ~ 30-80 mW envelope and retired the dominant open-question concern.
    That was wrong: the BBO buildup cavity at the in-house operating point
    converts only ~ 10 % visible-to-UV ([Guth21] §3.4 measured 78(5) mW UV
    from 780(15) mW visible; [Frie06] reports ~ 7 % at 1.4 W visible). To
    deliver 50 mW UV the BBO ring needs ~ 500 mW @ 559 nm at its input.
    The visible-output-scaling question therefore rem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
2026-05-09 docs(architectures): apply 2026-05-08 review priorities P1-P6 + file Council-3 task-split trigger
    Lands the architecture-tightening response to the 2026-05-08 review at
    logbook/2026-05-08-architecture-review-tightening-specs.md. Six of nine
    priority items addressed in this commit (P1-P6); three deferred to
    notebook / FEA / literature-extraction work and explicitly flagged
    (P7-P9).
    Top two priority actions per the review:
    P6 (highest leverage) - Council-3 deliberation trigger filed:
    logbook/2026-05-09-council-3-trigger-task-split-success-criterion.md
    Files Charter §9 trigger questions for the multi-architecture
    task-split success criterion. Asks Council-3 to dispose of th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
2026-05-13 docs(components): archive home-built doublers + fold-angle survey
    Top-view photographs of three currently-fielded 559 -> 280 nm BBO ring
    cavities of the Bermuda 25Mg+ apparatus (BD / Raman / RD) archived under
    docs/assets/components/home-built-doublers/. New components page
    docs/components/home-built-doublers.md applies the Charter idiom and
    records per-doubler O / O* / OPEN observations cross-walked to
    inventory.md and friedenauer-baseline.md.
    Photogrammetric fold-angle extraction (mirror-substrate pixel coords on
    each kinematic mount -> angle between long-arm and short-arm vectors at
    each curved-mirror vertex): BD ~ 26 deg, Raman ~ 29 deg, RD ~ 25 deg,
    all +/- 5 deg from substrate-centre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
2026-05-13 docs(literature): file task-E third scout pass — three new scaffolds + Burkley2021 correction
    File Hannig2018 (RSI 89, 013106 — 130 h CW BBO bow-tie at 313 nm), Shaw2021
    (Opt. Express 29, 37140 — 2 W CW LBO+CLBO at 261.5 nm), and Kraus2022
    (Opt. Express 30, 44992 — PPLN+DKDP single-pass at 267.4 nm with <5e-17
    phase stability) as SCAFFOLD entries in data/literature/. Correct the
    2026-05-06 Burkley2021 scaffold authorship (was internally attributed to
    "vonMilczewski" from a pre-PDF metadata guess; folder name was always
    correct). Append a third scout pass section to the task-E logbook
    cross-walking the 16-file downloads/literature/task-e/ batch to folder
    status, and file a companion 2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
2026-05-20 docs(logbook): open BBO coating-run WP — BC-A/B/C closed in one day
    Steward-deliberated work program for new BBO ring coatings keyed to two
    559 nm input scenarios (0.5 W / 1.5 W), with Friedenauer 2006 §D
    geometry held fixed and only coatings + substrate + LIDT free. Workplan
    went through four review rounds (v0 → v3) closing reviewer-flagged
    inconsistencies on loss-model normalisation, vendor-spec sign, and the
    γ-vs-T_IC_opt acceptance criterion.
    Phases executed in one calendar day:
    - BC-A · loss-model normalisation gate. Pinned γ_SHG_BBO = 1.4914e-4 W⁻¹
    from Phase E; pinned L_passive_PHE = 15 288 ppm by forward-solving the
    published 0.275 W UV at the Friedenauer corner; spl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
2026-05-20 docs(architectures): public-facing explainer for the BBO coating-run WP
    Add a Jekyll-rendered page for the trapped-ion / atomic-physics
    community walking through the rationale, math, and references behind
    the 2026-05-20 BBO coating-run work program.
    The page is aimed at builders running Friedenauer-class CW SHG ring
    cavities and is structured around the headline finding: re-running
    Friedenauer 2006's published BBO ring through the architecture-neutral
    cavity solver in src/ with the Phase-E-validated γ_SHG_BBO and the
    forward-solved L_passive_PHE reproduces the published 0.275 W UV
    exactly, and puts the impedance-matched optimum at T_IC_opt ≈ 0.0217
    — about +0.57 pp above the procured T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
2026-05-20 docs(architectures): fix four content errors in BBO coating-run page
    Public-facing reviewer flagged three substantive content errors and
    one rigor note on the explainer. All four fixed; no numerical
    change to the underlying analysis.
    1. M1' ↔ M4' confusion (4 sites). The input coupler with R = 0.984
    is M1' (the plane input coupler on the long arm), not M4'
    (the curved dichroic output coupler with R > 0.998 + T > 0.94).
    Fixed in:
    - bbo-coating-run.md frontmatter description
    - bbo-coating-run.md TL;DR bullet 1
    - docs/architectures/index.md row
    - docs/architectures/next-gen.md row
    2. Tolerance pp regression. v1 said ΔT_IC_opt = 0.54 pp is "below
    a typical single IBS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
2026-05-21 docs(architectures): add shareable BBO coating brief (sanitized)
    A recipient-agnostic standing brief for the 559->280 nm CW BBO doubler
    coating spec, meant to be linked from short emails. Carries the decision
    narrative, the four-mirror targets, and the open questions (coating
    feasibility, atmosphere near the SHG, BBO vs CLBO). No individual names,
    email, institution, or internal governance terms; links to the fuller
    companion explainer for depth.
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2026-06-26 docs(tutorials): add VECSEL systems tutorial (1118 nm + 1141 nm)
    New pedagogical page docs/tutorials/vecsel-systems.md explaining the two
    in-house VECSEL seed lasers — the ~1120 nm Doppler-cooling/detection/Raman
    seed (quadrupled to 280 nm) and the ~1140 nm photoionisation seed (to
    285 nm). Built around three pillars per steward direction:
    1. gain-mirror properties (RPG quantum wells, class-A dynamics,
    gain-peak temperature sensitivity, Henry alpha factor);
    2. the intracavity Lyot/BRF + YAG-etalon + PZT filtering hierarchy
    and the single-frequency mode-selection budget;
    3. the parameter sensitivities that limit linewidth (cavity-length
    noise ledger; chiller-cycle, the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
2026-06-26 docs(tutorials): revise VECSEL tutorial for newcomers + add figures
    Acts on the newcomer-focused review of the VECSEL systems tutorial:
    - "What you will learn" objectives box and a Key-terms glossary up top;
    inline glosses (DBR, RPG, ASE, BRF/Lyot, Fabry-Perot, mode-hop-free,
    RIN, Henry alpha) at first use; one-line Coastline/Sail explainer.
    - Two SVG figures (first content figures in the docs): a nested
    filter/mode-selection hierarchy and a frequency->amplitude-noise
    conversion chain, both on the site colour palette.
    - Scale/intuition callouts (72 GHz ~ 0.30 nm ~ 60 cavity modes;
    101 kHz vs 18 kHz reconciled via in-band noise density).
    - "Common misconception" w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
2026-06-26 docs+data: add 2021 VECSEL lab-note extraction; fold in-house numbers into tutorial
    Lab note (Evernote ENEX -> Markdown):
    - data/lab notes/2021-07-vecsel-project-summary.md — the in-house fleet
    summary (#1–#5), assembly/optical-element details, and the VECSEL #2
    frequency-noise budget. Binary attachments (photos/plots/PDFs) and the
    source .enex are kept local-only via .gitignore; only the converted text
    is committed.
    Tutorial now cites primary in-house values in place of literature stand-ins:
    - §2 filter stack: étalon FSR ≈73 GHz (1120 nm) / ≈70 GHz (1140 nm),
    BRF Brewster angle 57.15°, cavity L = 127.5 mm (FSR ≈1.18 GHz),
    1.5% output coupler (R ≈9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
2026-06-26 docs(tutorials): rigor pass on VECSEL tutorial (reviewer findings)
    - §3.4 (High): the linewidth criterion is now a transfer-function statement
    — the SHG cavities respond to residual frequency-noise spectral density
    S_δν(f) shaped by the cavity/servo, not the integrated linewidth. The old
    Δν_seed≪18 kHz inequality is demoted to a sanity check.
    - Fixed a below/above lock-bandwidth error: the lock TRACKS OUT noise below
    ~18 kHz; the residual noise ABOVE the lock bandwidth is what converts to
    amplitude noise. Corrected figure caption, alt text, the "for scale" box,
    and the conversion SVG.
    - Spanke 2025 (High): no longer claimed "sub-100 kHz"/"met ≤100 kHz";
    101(8) kHz no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
2026-06-26 docs: align seed-lasers page with transfer-function framing; tuning/§4/§5 fixes
    - seed-lasers.md (High): replaced the Δν_seed≪min(...) inequality and the
    "ratio to 18 kHz bounded" wording with the transfer-function statement —
    the binding quantity is the residual frequency-noise PSD above the ~18 kHz
    lock bandwidth; integrated linewidth is only a proxy. Now consistent with
    vecsel-systems.md §3.4.
    - tutorial tuning table: étalon-temperature row corrected to ~10 GHz before a
    mode hop ([Span25]) — the ≈73 GHz FSR is peak spacing, not a continuous
    span; PZT row corrected to ~1 GHz piezo travel (neXt) vs ~100 MHz (Nr.4).
    - tutorial top summary: 1141 nm row no longer "und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
2026-09-10 feat(tutorials): teach VECSEL principles and technical frequency noise
    Add a fifth Colab-ready notebook with five original figures covering the gain
    chip, cavity, ideal filters, technical frequency-noise PSDs and field coherence.
    Keep synthetic parameters editable and label the lesson pre-G1 exploratory.
    Explain the distinction between laser-frequency feedback and a following SHG
    cavity; align the narrative companion and link both from the student guide.
    Extend scoped runtime checks and manifest generation for the new self-contained
    inputs. Record environment and hashes; refresh only the RC-07 renderer hash.
    Existing four tutorials, core source and numerical review outputs are unchanged.
    V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
    [05-vecsel-principles-noise.py]
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

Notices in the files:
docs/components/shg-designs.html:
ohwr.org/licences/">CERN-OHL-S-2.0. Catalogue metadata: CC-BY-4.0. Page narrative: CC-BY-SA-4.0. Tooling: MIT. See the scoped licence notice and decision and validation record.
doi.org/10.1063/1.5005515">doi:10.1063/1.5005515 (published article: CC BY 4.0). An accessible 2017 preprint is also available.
